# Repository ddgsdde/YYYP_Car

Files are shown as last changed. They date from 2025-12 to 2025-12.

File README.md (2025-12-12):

# 智能车循迹系统 - Smart Car Line Follower System

## 📋 项目概述

这是一个**简化且稳定**的智能车循迹控制系统，基于ESP32-S3开发，专注于**高性能PID循迹控制**。

### 🎯 设计理念
- **专注核心功能**：纯循迹，无额外任务干扰
- **PID+权重算法**：精确控制，平滑跟线
- **实时可调参数**：Web界面动态调整，无需重新编译
- **增强稳定性**：完善的异常处理和状态机设计
- **调试友好**：三级调试系统（串口+OLED+Web）

## ✨ 核心功能

1. **权重+PID循迹** - 8通道加权位置计算 + PID差速控制
2. **按键启停控制** - 一键启动/停止，长按重置统计
3. **Web实时调试** - 参数在线调整、传感器监控、手动控制
4. **动态速度调整** - 根据偏差自动调整基础速度
5. **智能丢线处理** - 基于历史位置的搜索策略
6. **运行统计** - 循环频率、运行时间、里程记录

## 🔧 硬件配置

### 主控
- ESP32-S3-R8N16 (8MB PSRAM + 16MB Flash)

### 传感器
- 8通道循迹传感器模块 (UART通信，115200波特率)
- 0.96寸 OLED显示屏 (SSD1306)
- VL53L0X 激光测距模块
- 超声波测距模块 (3.3V)

### 执行器
- 2个AS4950驱动的减速电机 (减速比21.7)
- AB相编码器 (11PPR)
- 声光报警器
- 舵机 (可选)

### 车辆参数
- 车长: 15cm
- 车宽: 19.18cm  
- 轮胎直径: 67.6mm
- 轮胎宽度: 26.4mm

## 📦 物料清单 (BOM)

1. **PCB**: 查看嘉立创`EDA`工程的`BOM`表（注意：第一个板不用打，超尺寸了已弃用）。**PCB工程文件位于项目根目录的 `Files/` 文件夹中。**
2. **车架**: `3D`打印车底座。**3D打印模型文件位于项目根目录的 `Files/` 文件夹中。**
3. **动力系统**: 两个编码器电机 + 轮胎等
4. **测距模块**: `VL53L0X`激光测距模块
5. **避障模块**: 超声波模块（**必须使用3.3V供电**）
6. **辅助轮**: 一个小万向轮
7. **连接线**: 杜邦线等，按照自己需求购买线缆连接

## ⚠️ 组装注意事项

1. **焊接测试**: 焊接完毕后测试正常直接安装即可。
2. **MCU焊接**: 在焊接`mcu`模块时，如果使用锡膏要注意按键是否短路，短路会导致`esp32s3`无法正常启动。
3. **开发环境**: `Vscode`中必须安装`PlatformIO`拓展，编译后使用USB连接编译并烧录固件。
4. **烧录供电**: 烧录固件时主板必须处于通电状态。
5. **传感器安装**: 激光传感器建议用双面胶和胶带粘在侧方。

## 📌 引脚连接 (GPIO对应表)

| GPIO | 功能 | 说明 |
|---|---|---|
| IO8  | MS1 | 舵机PWM |
| IO3  | ECHO | 超声波 |
| IO18 | TX | 循迹模块 |
| IO46 | O | 声光报警高电平 |
| IO17 | RX | 循迹模块 |
| IO9  | 1A | 右电机编码器 |
| IO16 | SDA | 外设 (VL53L0X)  |
| IO10 | 1B | 右电机编码器 |
| IO15 | SCL | 外设 (VL53L0X)  |
| IO11 | 2A | 左电机编码器 |
| IO7  | 2I1 | 左电机 |
| IO12 | 2B | 左电机编码器 |
| IO6  | 2I2 | 左电机 |
| IO13 | SCL2 | 屏幕 |
| IO5  | 1I1 | 右电机 |
| IO14 | SDA2 | 屏幕 |
| IO4  | 1I2 | 右电机 |
| IO1  | SW1 | 实体按键（按下接通GND） |
| IO2  | TOUCH2 | 触摸按键 |
| IO45 | EN3V3  | 3.3V外设供电使能 |
| IO39 | TRIG | 超声波 |

## 🚀 快速开始与使用指南

### 1. 推荐流程
1. **硬件准备**: 定制PCB并完成焊接操作，测试`5v，3.3v`电压及电机驱动是否工作正常。
2. **固件烧录**: 
   - **下载编辑器**: 前往官网下载并安装 [Visual Studio Code](https://code.visualstudio.com/)。
   - **安装插件**: 打开 VSCode，在左侧扩展商店 (Extensions) 搜索 `PlatformIO IDE` 并安装（安装过程可能较慢，请耐心等待完成后重启软件）。
   - **打开项目**: 使用 VSCode 打开本项目的文件夹。
   - **编译烧录**: 等待左下角加载完毕后，使用 USB 连接主板（确保主板已通电），点击底部状态栏的 ➡️ (Upload) 箭头图标即可自动编译并烧录。
   
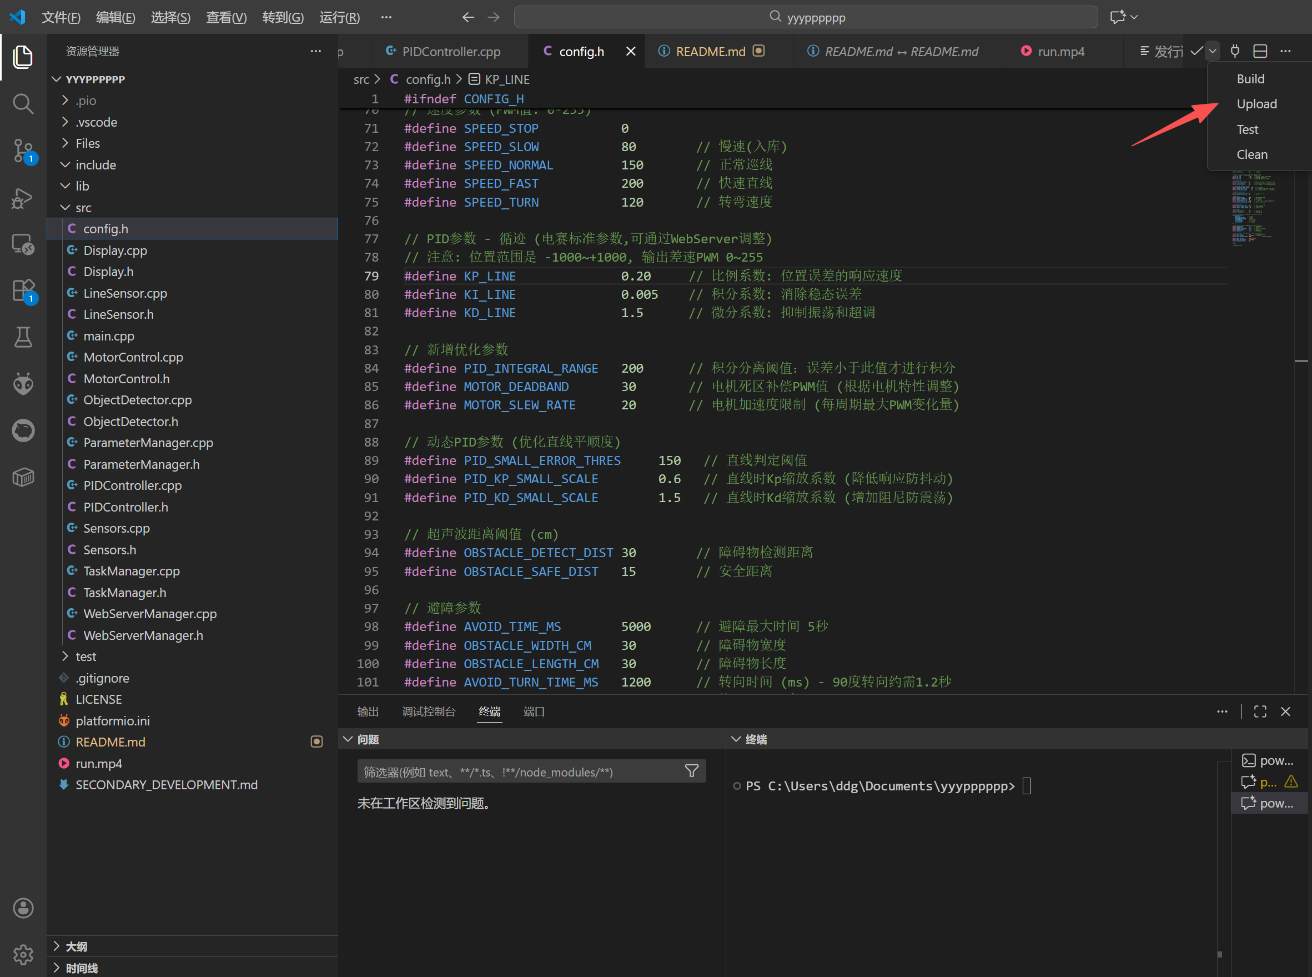
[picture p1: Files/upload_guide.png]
固件烧录指南
   

3. **整车组装**: 打印车模并安装，安装激光传感器等外设。
4. **参数调试**: 开始调参。

### 2. 编译上传

```bash
platformio run --target upload
```

### 3. 连接与调试

1. **WiFi连接**: 系统启动后会自动创建WiFi热点 `SmartCar_AP` (密码: `12345678`)。
2. **Web调试**: 连接WiFi后，浏览器访问 `http://192.168.4.1` 即可进行调试（上位机已内置）。
3. **操作控制**: 
   - **短按**物理按钮即可发车。
   - **再次短按**停止（注意：由于使用任务机制，在执行某些特定任务时可能无法立即停止）。

### 4. 检测传感器

页面会自动检测传感器状态，确保循迹传感器和编码器正常工作。

### 5. 调整参数

在Web界面中实时调整:
- **PID参数** (Kp=0.20, Ki=0.005, Kd=1.5 为推荐起始值)
- **速度参数** (慢速、正常、快速、转弯)
- **传感器权重** (默认 -1000 到 +1000 线性分布)

### 6. 开始循迹

1. 将小车放在黑线上
2. **短按**启动按键 → 开始循迹
3. **再次短按** → 停止循迹
4. **长按2秒** → 重置运行统计

## 📊 Web调试界面功能

### 实时状态监控
- **系统状态**: 运行/待机、运行时间
- **传感器数据**: 循迹位置 (-1000~+1000)、传感器状态 (0xFF)
- **PID调试**: P/I/D 三项实时数值
- **电机数据**: 左右轮速度 (mm/s)、里程 (mm)
- **性能指标**: 循环频率 (Hz)、丢线状态

### 参数实时调整
- **PID参数**: Kp (比例)、Ki (积分)、Kd (微分)
- **速度档位**: 慢速 (80)、正常 (150)、快速 (200)、转弯 (120)
- **传感器权重**: 8个传感器独立权重配置
- **保存功能**: Flash存储，断电不丢失

### 传感器检测
- **自动检测**: 页面加载自动检测所有传感器
- **实时刷新**: 500ms更新频率
- **状态指示**: ✅正常 / ❌异常 / ⏳检测中

### 手动控制
- **方向控制**: 前进、后退、左转、右转
- **特殊动作**: 180°原地转向
- **安全机制**: 暂停自动模式，松开停止

## 🎯 PID循迹算法详解

### 算法流程
```
1. 8通道传感器 → 加权位置计算 (-1000 ~ +1000)
2. 位置 → PID控制器 → 差速输出 (-255 ~ +255)
3. 基础速度 + 差速 → 左右轮速度
4. 动态调速：大偏差减速，小偏差加速
```

### 权重计算
```cpp
传感器: [0] [1] [2] [3] [4] [5] [6] [7]
权重:  -1000-750-500-250 250 500 750 1000
位置 = Σ(传感器i × 权重i) / Σ(传感器i × 1000)
```

### PID计算
```cpp
P项 = Kp × 位置误差       // 快速响应
I项 = Ki × Σ误差 × Δt     // 消除稳态误差
D项 = Kd × (误差变化率)   // 抑制振荡
输出 = P + I + D
```

### 动态速度策略
```cpp
if (|位置| > 700)  → 慢速 (80 PWM)
else if (|位置| > 400) → 中速 (115 PWM)
else → 正常速度 (150 PWM)
```

## ⚙️ PID调试技巧

### 推荐起始参数
```cpp
Kp = 0.20   // 比例：控制响应速度
Ki = 0.005  // 积分：消除稳态偏差
Kd = 1.5    // 微分：抑制振荡
```

### 调试步骤（Ziegler-Nichols方法改进版）

#### 第一步：调Kp
1. 设置 Ki=0, Kd=0
2. 从 Kp=0.1 开始逐渐增加
3. 观察：车子开始响应黑线
4. 继续增加直到出现**轻微振荡**
5. 记录此时的 Kp 值（称为 Ku）
6. 最终设置：**Kp = 0.6 × Ku**

#### 第二步：调Kd
1. 保持 Kp, Ki=0
2. 从 Kd=0.5 开始增加
3. 观察：振荡逐渐减小
4. 继续调整直到**平滑跟线，无振荡**
5. 推荐：**Kd = 1.5 ~ 3.0**

#### 第三步：调Ki（可选）
1. 保持 Kp 和 Kd
2. 从 Ki=0.001 开始增加
3. 观察：直线跑偏情况
4. 如果**无明显跑偏**，Ki保持很小或为0
5. 如果**持续偏向一侧**，增加 Ki
6. 注意：**Ki过大会导致超调**

### 常见问题及解决方案

| 现象 | 可能原因 | 解决方法 |
|---|---|---|
| 🐌 响应慢，转弯不及时 | Kp太小 | 增大Kp (步长0.05) |
| 🌊 左右摇摆严重 | Kp太大或Kd太小 | 减小Kp或增大Kd |
| ↗️ 直线持续偏向一侧 | Ki太小 | 增大Ki (步长0.002) |
| 🔄 过弯冲出赛道 | 速度太快 | 降低speedNormal |
| ⚡ 转弯时振荡 | Kd不足 | 增大Kd (步长0.5) |
| 💥 突然失控 | Ki太大导致积分饱和 | 减小Ki或重置系统 |

### 高级优化技巧

1. **权重调整**
   - 外侧传感器权重 ↑ → 转弯灵敏度 ↑
   - 内侧传感器权重 ↑ → 直线稳定性 ↑
   - 非线性权重：`[-1200, -800, -400, -150, 150, 400, 800, 1200]`

2. **动态速度**
   - 大偏差时自动减速（代码已实现）
   - 可根据赛道调整阈值 (700/400)

3. **丢线处理**
   - 系统已实现基于历史位置的智能搜索
   - 连续3次全白才判定丢线（避免误判）

4. **测试流程**
   ```
   低速测试 → 调PID → 中速测试 → 微调 → 高速测试 → 优化权重
   ```

## 🔍 调试模式

在`src/config.h`中可以开启不同的调试输出:

```cpp
#define DEBUG_SERIAL         true   // 串口调试
#define DEBUG_OLED           true   // OLED显示
#define DEBUG_LINE_SENSOR    false  // 循迹详细信息
#define DEBUG_ENCODER        false  // 编码器输出
#define DEBUG_PID            true   // PID三项数值
```

### 串口输出示例
```
Pos: -450 | P: -90.0 I:  -2.3 D: 120.5 | Out: 28.2 | L: 164 R: 136
Pos:  320 | P:  64.0 I:   1.8 D: -85.3 | Out:-19.5 | L: 130 R: 170
```

### OLED显示内容
```
RUN  T:45s          ← 状态和运行时间
S:0x18 P:0          ← 传感器状态和位置
P:0 I:0 D:0         ← PID三项
L:150 R:150         ← 左右轮速
─────────────────
Dist:12.5m          ← 累计里程
Freq:95Hz           ← 循环频率
```

## 📦 代码结构

```
src/
├── main.cpp              # 主程序和状态机
├── config.h              # 配置参数
├── LineSensor.h/cpp      # 循迹传感器
├── MotorControl.h/cpp    # 电机控制和编码器
├── PIDController.h/cpp   # PID控制器
├── Sensors.h/cpp         # 超声波和激光传感器
├── Display.h/cpp         # OLED显示
├── ParameterManager.h/cpp     # 参数管理和存储
└── WebServerManager.h/cpp     # Web服务器
```

## 🛠️ 依赖库

- ESP32Encoder - 编码器读取
- QuickPID - PID控制
- Adafruit_VL53L0X - 激光测距
- NewPing - 超声波测距
- Adafruit GFX & SSD1306 - OLED显示
- ESPAsyncWebServer - Web服务器
- ArduinoJson - JSON数据处理
- Preferences - 参数持久化存储

## 🎯 比赛任务清单

- [x] 循迹行驶
- [x] 物体长度测量
- [x] 障碍物避障 (偏出时间≤5秒)
- [x] 自动入库停车
- [x] 声光报警
- [x] 实时调试

## 📝 注意事项

1. **首次使用** - 先在测试环境调试PID参数
2. **光照影响** - 循迹传感器对光照敏感,建议现场校准
3. **电池电压** - 确保电池电量充足,电压不足会影响电机性能
4. **Web连接** - 比赛时可以连接Web界面实时监控
5. **参数备份** - 调好参数后记得保存,断电会丢失临时参数

## 🐛 故障排查

### 小车不走
- 检查电机连接
- 检查PWM输出
- 串口监视器查看日志

### 循迹不准
- 调整PID参数
- 检查传感器安装高度
- 查看Web界面传感器状态

### Web连接不上
- 确认WiFi已连接到SmartCar_AP
- 检查IP地址 (192.168.4.1)
- 查看串口输出的IP地址

### 避障失败
- 调整超声波阈值
- 增加避障距离参数
- 检查避障逻辑

## 📈 性能优化建议

1. **速度优化** - 直线段提高速度,弯道降低速度
2. **响应优化** - 根据场地调整PID参数
3. **避障优化** - 根据障碍物大小调整避障路径
4. **测量优化** - 激光传感器采样多次取平均

## 🏆 比赛策略

1. **稳定优先** - 初期以稳定完成为目标
2. **速度提升** - 稳定后逐步提高速度
3. **参数微调** - 根据现场情况微调参数
4. **多次测试** - 比赛前多次完整测试

## 🎬 比赛视频

> 由于 GitHub README 的安全限制，无法直接嵌入仓库内的视频文件进行内联播放。
> 请点击下方链接，跳转到 GitHub 播放器观看：

[**▶️ 点击观看比赛演示视频 (run.mp4)**](https://github.com/ScineceTechAILab/YYYP_Car/blob/master/run.mp4)

## 📞 技术支持

如有问题,请检查:
1. 串口监视器输出 (115200波特率)
2. Web界面实时状态
3. OLED显示屏信息

## 📄 版本信息

- Version: 1.0.0
- Date: 2025-01-13
- Platform: ESP32-S3
- Framework: Arduino

## 📜 开源协议

本项目采用 [GPL-3.0](LICENSE) 开源协议。
您可以自由地使用、修改和分发本项目代码，但必须保留原作者版权声明，且分发的衍生作品也必须采用相同的 GPL-3.0 协议开源。

---

**祝比赛顺利! 🏁**

POWERED BY DDG

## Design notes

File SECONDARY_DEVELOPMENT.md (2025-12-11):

# 智能循迹小车二次开发文档

本文档旨在帮助开发者理解项目架构，并进行二次开发（如添加新功能、修改控制逻辑、增加参数等）。

## 1. 项目简介

本项目是一个基于 ESP32-S3 的智能循迹小车系统，具备以下核心功能：
- **高精度循迹**：基于 PID 算法的黑线循迹。
- **多阶段控制**：支持测距前、测距后使用不同的 PID 和速度参数。
- **智能避障**：基于超声波和编码器的多步避障逻辑（左转->直行->平行->回线）。
- **物块测量**：使用激光测距传感器测量路边物块长度。
- **自动入库**：识别终点并自动入库停车。
- **Web 交互**：通过 WiFi 提供 Web 界面，支持实时参数调整、状态监控和日志查看。

## 2. 开发环境搭建

1.  **IDE**: Visual Studio Code
2.  **插件**: PlatformIO IDE
3.  **硬件**: 4D Systems GEN4-ESP32 16MB (ESP32S3-R8N16) 或兼容 ESP32S3 开发板。
4.  **依赖库** (自动安装):
    - `ESP32Encoder`, `QuickPID` (运动控制)
    - `Adafruit_VL53L0X`, `NewPing` (传感器)
    - `ESPAsyncWebServer`, `ArduinoJson` (网络与数据)
    - `Adafruit SSD1306`, `Adafruit GFX` (OLED 显示)

## 3. 项目结构说明

```text
├── platformio.ini      # PlatformIO 配置文件 (依赖、板卡定义)
├── src/                # 源代码目录
│   ├── main.cpp        # 主程序入口，包含状态机和主循环
│   ├── config.h        # 全局硬件引脚定义和常量
│   ├── ParameterManager.*  # 参数管理 (NVS存储、JSON序列化)
│   ├── WebServerManager.*  # Web 服务器与 WebSocket 通信
│   ├── MotorControl.*      # 电机底层驱动与编码器读取
│   ├── PIDController.*     # PID 算法实现
│   ├── LineSensor.*        # 循迹传感器处理
│   ├── Sensors.*           # 综合传感器管理 (激光、超声波等)
│   ├── ObjectDetector.*    # 物块检测与测量逻辑
│   ├── TaskManager.*       # 任务队列管理
│   └── Display.*           # OLED 显示管理
└── include/            # 头文件目录
```

## 4. 核心架构解析

### 4.1 系统状态机 (`main.cpp`)
系统通过 `SystemState` 枚举管理运行状态：
- `STATE_IDLE`: 待机状态，电机停止。
- `STATE_LINE_FOLLOW`: 循迹模式，核心控制逻辑。
- `STATE_OBSTACLE_AVOID`: 避障模式，执行多步避障动作。
- `STATE_PARKING`: 入库模式，执行停车逻辑。
- `STATE_TESTING`: 测试模式，用于调试特定动作（如转弯、直行）。

### 4.2 参数管理系统 (`ParameterManager`)
所有可配置参数（PID、速度、阈值等）都存储在 `ParameterManager` 中。
- **存储**: 使用 ESP32 `Preferences` (NVS) 掉电保存。
- **交互**: 提供 `toJson()` 和 `fromJson()` 方法，方便与 Web 端交互。

### 4.3 Web 交互系统 (`WebServerManager`)
- 基于 `ESPAsyncWebServer`。
- 前端 HTML/JS 硬编码在 `generateHTML()` 中（为了单文件部署便利）。
- 通过 HTTP GET/POST 接口交换 JSON 数据。

## 5. 常见开发场景指南

### 5.1 如何添加一个新的配置参数？

如果你需要添加一个新的参数（例如 `newParam`），请遵循以下步骤：

1.  **修改 `src/ParameterManager.h`**:
    在 `Parameters` 结构体中添加变量：
    ```cpp
    struct Parameters {
        // ... existing params
        float newParam; // [新增]
    };
    ```

2.  **修改 `src/ParameterManager.cpp`**:
    - 在构造函数中设置默认值：
      ```cpp
      newParam = 1.0f;
      ```
    - 在 `load()` 方法中读取 NVS：
      ```cpp
      newParam = prefs.getFloat("newParam", 1.0f);
      ```
    - 在 `save()` 方法中写入 NVS：
      ```cpp
      prefs.putFloat("newParam", newParam);
      ```
    - 在 `toJson()` 方法中添加到 JSON：
      ```cpp
      doc["newParam"] = newParam;
      ```
    - 在 `fromJson()` 方法中从 JSON 读取：
      ```cpp
      if (doc.containsKey("newParam")) newParam = doc["newParam"];
      ```

3.  **修改 `src/WebServerManager.cpp`**:
    在 `generateHTML()` 的 JavaScript 部分，找到 `loadParams` 和 `saveParams` 函数，添加对应的字段映射，并在 HTML 表单中添加 `<input>` 元素。

### 5.2 如何修改避障逻辑？

避障逻辑位于 `src/main.cpp` 的 `handleObstacleAvoidance()` 函数中。
它是一个基于 `avoidSubState` 的子状态机：
1.  `AVOID_TURN_LEFT`: 左转离开赛道。
2.  `AVOID_FORWARD_OUT`: 直行一段距离。
3.  `AVOID_TURN_RIGHT_1`: 右转平行。
4.  ...

**修改建议**:
- 调整 `ParameterManager` 中的 `avoid*` 相关参数（如 `avoidTurn1Dist`）通常能满足大部分需求。
- 如果需要修改动作顺序，请直接修改 `switch(avoidSubState)` 中的逻辑跳转。

### 5.3 如何添加新的传感器？

1.  **硬件连接**: 确定引脚并在 `src/config.h` 中定义。
2.  **驱动封装**: 建议在 `src/Sensors.h/.cpp` 中添加初始化和读取代码，或者创建新的类。
3.  **数据集成**: 在 `src/main.cpp` 的 `updateSensors()` 中调用更新，并通过 `getSystemStatus()` 将数据发送到 Web 端以便调试。

## 6. 调试技巧

- **串口调试**: 波特率 `115200`。系统启动时会打印详细信息。
- **Web 日志**: 浏览器访问小车 IP，页面底部有实时 Console 日志，通过 `webServer.addLog()` 输出。
- **OLED 显示**: 实时显示 PID 输出、传感器状态和 IP 地址。
- **状态监控**: Web 界面会以 5Hz 频率刷新 JSON 状态，包含所有传感器数据和内部变量。

## 7. 编译与上传

在 VS Code 终端中运行：

- **编译**: `platformio run`
- **上传**: `platformio run --target upload`
- **清理**: `platformio run --target clean`

## 8. 注意事项

- **并发安全**: `WebServer` 回调在独立任务中运行，修改全局变量（如 `currentState`）时需注意线程安全，或使用标志位（如 `pendingManualCmd`）在主循环中处理。
- **NVS 寿命**: 避免在循环中高频调用 `params.save()`，这会损耗 Flash 寿命。仅在 Web 端点击“保存”时调用。

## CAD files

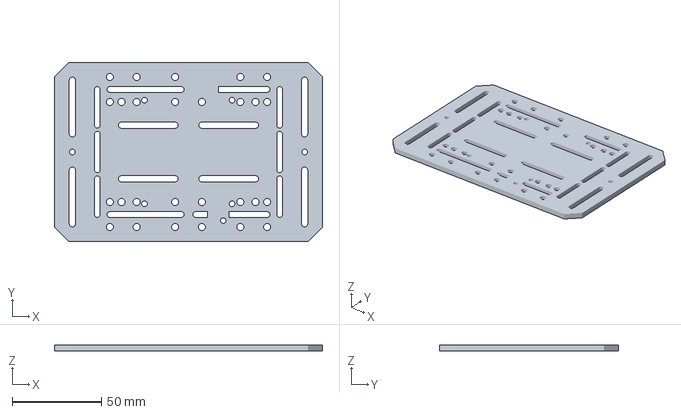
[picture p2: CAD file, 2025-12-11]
Files/3D/组合体.3mf
150.0 x 100.0 x 3.50 mm

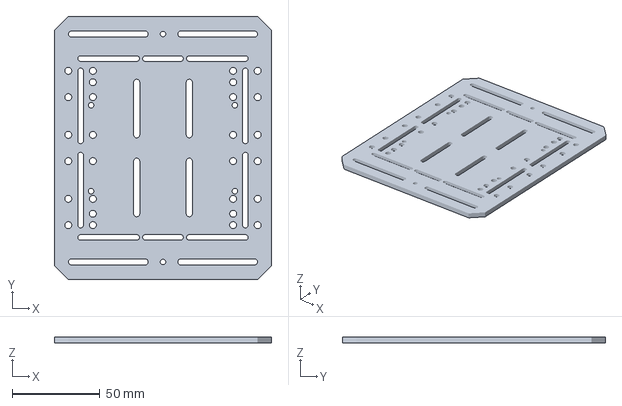
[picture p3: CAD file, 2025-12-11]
Files/3D/组合放大体.3mf
124.0 x 150.0 x 3.50 mm

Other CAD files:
Files/3D/组合体.stl

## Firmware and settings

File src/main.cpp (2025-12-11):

#include <Arduino.h>
#include <ArduinoJson.h>
#include "config.h"
#include "LineSensor.h"
#include "MotorControl.h"
#include "Sensors.h"
#include "Display.h"
#include "PIDController.h"
#include "ParameterManager.h"
#include "WebServerManager.h"
#include "ObjectDetector.h"
#include "TaskManager.h"

// 全局对象
LineSensor lineSensor;
MotorControl motor;
Sensors sensors;
Display display;
PIDController pidController(KP_LINE, KI_LINE, KD_LINE);
PIDController encoderPid(1.0, 0, 0); // 编码器直线保持PID
ParameterManager params;
WebServerManager webServer(&params);
ObjectDetector objectDetector(&sensors, &motor);
TaskManager taskManager;

// 状态变量
SystemState currentState = STATE_IDLE;
bool systemRunning = false;  // 系统运行标志

// 跨任务通信标志 (解决并发崩溃问题)
volatile bool pendingTestTurn = false;
volatile bool pendingTestStraight = false;
volatile bool pendingTestAvoid = false;
volatile bool pendingTestParking = false;
enum ManualCommand { CMD_NONE, CMD_STOP, CMD_FORWARD, CMD_BACKWARD, CMD_LEFT, CMD_RIGHT, CMD_TURN_180 };
volatile ManualCommand pendingManualCmd = CMD_NONE;
volatile float pendingManualValue = 0;

// 障碍物检测计数器
int obstacleDetectCount = 0;  // 检测到的障碍物次数
bool obstacleDetectionEnabled = false;  // 是否启用障碍物检测

// 避障子状态
enum AvoidanceSubState {
    AVOID_NONE,
    AVOID_TURN_LEFT,      // 1. 左转离开赛道
    AVOID_FORWARD_OUT,    // 2. 直行离开赛道 (距离可调)
    AVOID_TURN_RIGHT_1,   // 3. 右转 (平行于赛道)
    AVOID_FORWARD_PARALLEL, // 4. 直行 (平行移动)
    AVOID_TURN_RIGHT_2,   // 5. 右转 (面向赛道)
    AVOID_FORWARD_IN,     // 6. 直行寻找黑线
    AVOID_TURN_LEFT_ALIGN // 7. 左转对齐赛道
};
AvoidanceSubState avoidSubState = AVOID_NONE;
unsigned long avoidStateStartTime = 0;
float avoidStateStartDistance = 0;
float avoidStartLeftDist = 0;
float avoidStartRightDist = 0;

// 避障后状态变量
unsigned long avoidanceFinishTime = 0; // 避障完成时间
bool postAvoidanceStable = false;      // 避障后是否已稳定(持续1秒识线)

// 停车子状态
enum ParkingSubState {
    PARK_APPROACH,      // 接近 (减速)
    PARK_VERY_SLOW,     // 极慢速
    PARK_STOP,          // 停止
    PARK_ALARM          // 报警
};
ParkingSubState parkingSubState = PARK_APPROACH;
unsigned long parkingStateStartTime = 0;

// 测试模式状态
enum TestSubState {
    TEST_NONE,
    TEST_TURN_90,
    TEST_STRAIGHT_1M
};
TestSubState currentTestState = TEST_NONE;
unsigned long testStartTime = 0;

// 按键状态机变量
unsigned long buttonPressStart = 0;
bool buttonWasPressed = false;
bool buttonProcessed = false;  // 防止重复触发

// 手动控制变量
bool manualControlActive = false;
unsigned long manualControlEndTime = 0;

// 循迹统计变量
unsigned long lineFollowStartTime = 0;
unsigned long totalLineFollowTime = 0;
uint32_t loopCounter = 0;
unsigned long lastStatsTime = 0;

// 状态回调函数
String getSystemStatus() {
    JsonDocument doc;
    
    // 系统状态
    const char* stateNames[] = {"IDLE", "LINE_FOLLOW", "OBSTACLE_AVOID", "PARKING", "FINISHED", "TESTING"};
    if (currentState >= 0 && currentState < sizeof(stateNames)/sizeof(stateNames[0])) {
        doc["state"] = stateNames[currentState];
    } else {
        doc["state"] = "UNKNOWN";
    }
    doc["uptime"] = millis() / 1000;
    doc["running"] = systemRunning;
    doc["loopFreq"] = loopCounter;  // 循环频率
    
    // 传感器数据
    JsonObject sensor = doc["sensor"].to<JsonObject>();
    sensor["linePos"] = lineSensor.getLinePosition();
    sensor["lineStates"] = lineSensor.getRawStates();
    sensor["dataReady"] = lineSensor.isDataReady();
    sensor["lostLine"] = lineSensor.isLostLine();
    sensor["laserDist"] = sensors.getLaserDistance();
    sensor["laserReady"] = sensors.isLaserReady();
    sensor["ultraDist"] = sensors.getUltrasonicDistance();
    
    // 电机数据
    JsonObject mot = doc["motor"].to<JsonObject>();
    mot["speedL"] = motor.getLeftSpeed();
    mot["speedR"] = motor.getRightSpeed();
    mot["distL"] = motor.getLeftDistance();
    mot["distR"] = motor.getRightDistance();
    mot["encL"] = motor.getLeftEncoder();
    mot["encR"] = motor.getRightEncoder();
    
    // PID调试数据
    JsonObject pid = doc["pid"].to<JsonObject>();
    pid["pTerm"] = pidController.getP();
    pid["iTerm"] = pidController.getI();
    pid["dTerm"] = pidController.getD();
    pid["error"] = pidController.getError();
    
    // 运行统计
    doc["totalTime"] = totalLineFollowTime / 1000;
    
    // 编码器调试信息
    JsonObject encDebug = doc["encDebug"].to<JsonObject>();
    encDebug["left"] = motor.getLeftDistance();
    encDebug["right"] = motor.getRightDistance();
    encDebug["diff"] = motor.getLeftDistance() - motor.getRightDistance();
    
    // 物块检测状态
    JsonObject detection = doc["detection"].to<JsonObject>();
    detection["active"] = objectDetector.isDetecting();
    detection["completed"] = objectDetector.isCompleted();
    if (objectDetector.isCompleted()) {
        ObjectMeasurement result = objectDetector.getResult();
        detection["length"] = result.length;
        detection["avgDist"] = result.avgDistance;
        detection["valid"] = result.valid;
        detection["duration"] = result.duration; // 新增：检测持续时间
        // 传递原始长度，避免前端反向计算误差
        float rawLen = (result.endPos - result.startPos);
        detection["rawLength"] = rawLen;
    }
    
    // 任务管理状态
    JsonObject tasks = doc["tasks"].to<JsonObject>();
    tasks["executing"] = taskManager.isExecuting();
    tasks["current"] = taskManager.getCurrentTaskIndex();
    tasks["total"] = taskManager.getTotalTasks();
    
    String output;
    serializeJson(doc, output);
    return output;
}

// 任务执行器 - 启动任务
bool executeTask(Task* task) {
    if (!task) return false;
    
    switch (task->type) {
        case TASK_LINE_FOLLOW:
            // 开启循迹模式
            systemRunning = true;
            currentState = STATE_LINE_FOLLOW;
            return true;
            
        case TASK_MEASURE_OBJECT:
            // 启动物块测量
            objectDetector.startDetection(
                task->params.laserBaseline, 
                task->params.laserThreshold
            );
            return true;
            
        case TASK_FORWARD:
            // 前进指定距离
            motor.resetEncoders();
            motor.setBothSpeed(task->params.speed > 0 ? task->params.speed : params.speedNormal);
            return true;
            
        case TASK_STOP:
            // 停止
            systemRunning = false;
            motor.stop();
            return true;
            
        case TASK_DELAY:
            // 延时（通过startTime判断）
            return true;
            
        case TASK_BEEP:
            // 蜂鸣
            // sensors.beep(task->params.duration > 0 ? task->params.duration : 100);
            return true;
            
        default:
            Serial.printf("⚠ Unknown task type: %d\n", task->type);
            return false;
    }
}

// 任务完成检查器
bool checkTaskCompletion(Task* task) {
    if (!task) return true;
    
    switch (task->type) {
        case TASK_LINE_FOLLOW:
            // 循迹任务需要手动停止或达到距离
            if (task->params.distance > 0) {
                float avgDist = motor.getAverageDistance();
                return avgDist >= task->params.distance;
            }
            return false;  // 无限循迹，需要其他条件停止
            
        case TASK_MEASURE_OBJECT:
            // 检查物块测量是否完成
            return objectDetector.isCompleted() || 
                   (millis() - task->startTime > 30000);  // 30秒超时
            
        case TASK_FORWARD:
            // 检查是否达到目标距离
            if (task->params.distance > 0) {
                float avgDist = motor.getAverageDistance();
                if (avgDist >= task->params.distance) {
                    motor.stop();
                    return true;
                }
            } else if (task->params.duration > 0) {
                // 按时间前进
                if (millis() - task->startTime >= task->params.duration) {
                    motor.stop();
                    return true;
                }
            }
            return false;
            
        case TASK_STOP:
            return true;  // 立即完成
            
        case TASK_DELAY:
            return (millis() - task->startTime) >= task->params.duration;
            
        case TASK_BEEP:
            return true;  // 立即完成
            
        default:
            return true;
    }
}

// 运动控制回调 (仅设置标志位，不在中断/异步任务中执行逻辑)
void handleMotionCommand(String action, float value) {
    // 映射字符串命令到枚举，确保原子操作
    if (action == "stop") pendingManualCmd = CMD_STOP;
    else if (action == "forward") pendingManualCmd = CMD_FORWARD;
    else if (action == "backward") pendingManualCmd = CMD_BACKWARD;
    else if (action == "left") pendingManualCmd = CMD_LEFT;
    else if (action == "right") pendingManualCmd = CMD_RIGHT;
    else if (action == "turn_180") pendingManualCmd = CMD_TURN_180;
    
    pendingManualValue = value;
}

// 处理挂起的命令 (在主循环中调用)
void processPendingCommands() {
    // 1. 处理测试命令
    if (pendingTestTurn) {
        pendingTestTurn = false;
        if (!systemRunning) {
            Serial.println("CMD: Starting Turn 90 Test");
            currentState = STATE_TESTING;
            currentTestState = TEST_TURN_90;
            testStartTime = millis();
            motor.resetEncoders();
            systemRunning = true;
        }
    }
    
    if (pendingTestStraight) {
        pendingTestStraight = false;
        if (!systemRunning) {
            Serial.println("CMD: Starting Straight 1m Test");
            currentState = STATE_TESTING;
            currentTestState = TEST_STRAIGHT_1M;
            testStartTime = millis();
            motor.resetEncoders();
            encoderPid.reset();
            encoderPid.setGains(params.encKp, params.encKi, params.encKd);
            systemRunning = true;
        }
    }
    
    if (pendingTestAvoid) {
        pendingTestAvoid = false;
        if (!systemRunning) {
            Serial.println("CMD: Starting Avoidance Test");
            // 直接进入避障状态
            currentState = STATE_OBSTACLE_AVOID;
            avoidSubState = AVOID_TURN_LEFT;
            avoidStateStartTime = millis();
            motor.resetEncoders();
            avoidStartLeftDist = 0;
            avoidStartRightDist = 0;
            avoidStateStartDistance = 0;
            systemRunning = true;
            // sensors.beep(100);
        }
    }

    if (pendingTestParking) {
        pendingTestParking = false;
        Serial.println("CMD: Starting Parking Test");
        
        // 重置系统状态
        systemRunning = true;
        currentState = STATE_LINE_FOLLOW;
        lineFollowStartTime = millis();
        motor.resetEncoders();
        pidController.reset();
        
        // 设置为入库测试模式
        objectDetector.stopDetection(); // 确保不处于物块检测模式
        obstacleDetectionEnabled = true; // 启用障碍物检测
        obstacleDetectCount = 1; // 假装已经避过第一个障碍物，下一个就是车库
        
        // sensors.beep(100);
        // delay(50);
        // sensors.beep(100);
        display.showDebug("TEST PARKING\nSearching...");
    }
    
    // 2. 处理手动控制命令
    if (pendingManualCmd != CMD_NONE) {
        ManualCommand cmd = pendingManualCmd;
        float val = pendingManualValue;
        pendingManualCmd = CMD_NONE; // 清除标志
        
        // 执行逻辑
        if (cmd == CMD_STOP) {
            motor.stop();
            manualControlActive = false;
            if (systemRunning) Serial.println("Manual Stop");
        } else {
            // 激活手动控制
            if (systemRunning) {
                Serial.println("Auto mode paused for manual control");
            }
            manualControlActive = true;
            
            int moveSpeed = (val > 0) ? (int)val : params.speedNormal;
            int turnSpeed = params.speedTurn;
            
            switch (cmd) {
                case CMD_FORWARD:
                    motor.setBothSpeed(moveSpeed);
                    manualControlEndTime = millis() + 10000;
                    break;
                case CMD_BACKWARD:
                    motor.setBothSpeed(-moveSpeed);
                    manualControlEndTime = millis() + 10000;
                    break;
                case CMD_LEFT:
                    motor.setLeftSpeed(-turnSpeed);
                    motor.setRightSpeed(turnSpeed);
                    manualControlEndTime = millis() + 10000;
                    break;
                case CMD_RIGHT:
                    motor.setLeftSpeed(turnSpeed);
                    motor.setRightSpeed(-turnSpeed);
                    manualControlEndTime = millis() + 10000;
                    break;
                case CMD_TURN_180:
                    motor.setLeftSpeed(turnSpeed);
                    motor.setRightSpeed(-turnSpeed);
                    manualControlEndTime = millis() + 1200;
                    break;
                default: break;
            }
        }
    }
}
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
void loop() {
    // 处理Web挂起的命令
    processPendingCommands();

    // 更新传感器数据
    updateSensors();
    
    // 按键状态机 - 改进的防抖和切换逻辑
    bool buttonNow = sensors.isButtonPressed();
    
    if (buttonNow && !buttonWasPressed && !buttonProcessed) {
        // 按钮刚按下
        buttonPressStart = millis();
        buttonWasPressed = true;
    } else if (!buttonNow && buttonWasPressed && !buttonProcessed) {
        // 按钮刚释放
        unsigned long pressDuration = millis() - buttonPressStart;
        
        if (pressDuration >= 50 && pressDuration < 2000) {
            // 有效短按：切换运行状态
            systemRunning = !systemRunning;
            buttonProcessed = true;
            
            if (systemRunning) {
                currentState = STATE_LINE_FOLLOW;
                lineFollowStartTime = millis();
                motor.resetEncoders();
                pidController.reset();  // 重置PID状态
                
                // 重置避障后状态
                avoidanceFinishTime = 0;
                postAvoidanceStable = false;
                
                // 自动启动物块检测
                currentState = STATE_LINE_FOLLOW;
                lineFollowStartTime = millis();
                motor.resetEncoders();
                pidController.reset();  // 重置PID状态
                
                // 自动启动物块检测
                objectDetector.setFilterSize(params.objectFilterSize);
                objectDetector.setCorrection(params.objectLengthScale, params.objectLengthOffset);
                objectDetector.startDetection(0, params.objectDetectDist);
                
                // 重置障碍物检测状态
                obstacleDetectCount = 0;
                obstacleDetectionEnabled = false;  // 等物块测量完成后再启用
                
                display.showDebug("RUNNING\nPress to stop");
            } else {
                // 停止
                Serial.println("\n=== SYSTEM STOP ===");
                // sensors.beep(200);
                
                motor.stop();
                currentState = STATE_IDLE;
                
                // 停止检测
                if (objectDetector.isDetecting()) {
                    objectDetector.stopDetection();
                }
                
                totalLineFollowTime += millis() - lineFollowStartTime;
                
                Serial.printf("✓ Total run time: %lu seconds\n", totalLineFollowTime / 1000);
                display.showDebug("STOPPED\nPress to start");
            }
        } else if (pressDuration >= 2000) {
            // 长按：重置统计
            totalLineFollowTime = 0;
            motor.resetEncoders();
            Serial.println("✓ Statistics reset");
            // sensors.beep(50);
            // delay(100);
            // sensors.beep(50);
            // delay(100);
            // sensors.beep(50);
            buttonProcessed = true;
        }
    } else if (!buttonNow && buttonProcessed) {
        // 按钮完全释放后重置处理标志
        buttonProcessed = false;
        buttonWasPressed = false;
    }
    
    // 手动控制模式处理
    if (manualControlActive) {
        if (millis() >= manualControlEndTime) {
            motor.stop();
            manualControlActive = false;
            Serial.println("✓ Manual control completed");
        }
        delay(10);
        return;  // 手动模式下不执行自动逻辑
    }
    
    // 更新任务管理器
    taskManager.update();

    // 定时更新Web状态 (200ms interval) - 解决并发崩溃问题的关键
    // 将状态生成移至主循环，避免Web任务直接访问共享资源
    static unsigned long lastWebUpdate = 0;
    if (millis() - lastWebUpdate > 200) {
        String status = getSystemStatus();
        webServer.updateStatusJson(status);
        lastWebUpdate = millis();
    }
    
    // 状态机
    switch (currentState) {
        case STATE_IDLE:
            motor.stop();
            break;
            
        case STATE_LINE_FOLLOW:
            if (systemRunning) {
                lineFollowControl();
            } else {
                motor.stop();
            }
            break;
            
        case STATE_OBSTACLE_AVOID:
            handleObstacleAvoidance();
            break;
            
        case STATE_PARKING:
            handleParking();
            break;
            
        case STATE_FINISHED:
            motor.stop();
            break;

        case STATE_TESTING:
            handleTestMode();
            break;
    }
    
    // 更新显示
#if DEBUG_OLED
    static unsigned long lastDisplayUpdate = 0;
    if (millis() - lastDisplayUpdate > 100) {
        int16_t linePos = lineSensor.getLinePosition();
        uint8_t states = lineSensor.getRawStates();
        
        display.clear();
        Adafruit_SSD1306* oled = display.getDisplay();
        if (oled) {
            oled->setCursor(0, 0);
            oled->setTextSize(1);
            
            // 第一行：状态
            oled->print(systemRunning ? "RUN " : "IDLE");
            oled->printf(" T:%lus\n", (millis() - lineFollowStartTime) / 1000);
            
            // 第二行：传感器状态
            oled->printf("S:0x%02X P:%d\n", states, linePos);
            
            // 第三行：PID输出
            oled->printf("P:%.0f I:%.0f D:%.0f\n", 
                pidController.getP(), 
                pidController.getI(), 
                pidController.getD());
            
            // 第四行：电机速度
            oled->printf("L:%d R:%d\n", 
                (int)motor.getLeftSpeed(), 
                (int)motor.getRightSpeed());
            
            // 分隔线
            oled->drawLine(0, 32, 128, 32, SSD1306_WHITE);
            
            // 如果有测量结果，优先显示结果
            if (objectDetector.getResult().length > 0) {
                oled->setCursor(0, 36);
                oled->setTextSize(1);
                oled->print("Len:");
                oled->setCursor(30, 34); // 稍微调整位置以适应大字体
                oled->setTextSize(3);    // 使用更大的字体
                oled->print((int)objectDetector.getResult().length);
                oled->setTextSize(1);
                oled->print("mm");
            } else {
                // 下半部分：里程和激光距离
                oled->setCursor(0, 36);
                oled->setTextSize(1);
                oled->printf("Dist:%.1fm\n", motor.getAverageDistance() / 1000.0);
                
                // 激光距离
                uint16_t laserDist = sensors.getLaserDistance();
                oled->printf("Laser:%dmm\n", laserDist);
                
                oled->printf("Freq:%dHz", loopCounter);
            }
        }
        
        display.update();
        lastDisplayUpdate = millis();
    }
#endif
    
    // 移除固定延时，全速运行
    // delay(10); 
}

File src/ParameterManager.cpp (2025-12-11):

#include "ParameterManager.h"
#include <ArduinoJson.h>

ParameterManager::ParameterManager() {
    // 默认值 (Phase 1)
    kp = KP_LINE;
    ki = KI_LINE;
    kd = KD_LINE;
    
    // 默认值 (Phase 2) - 默认与Phase 1相同
    kpPost = KP_LINE;
    kiPost = KI_LINE;
    kdPost = KD_LINE;
    
    speedSlow = SPEED_SLOW;
    speedNormal = SPEED_NORMAL;
    speedFast = SPEED_FAST;
    speedTurn = SPEED_TURN;
    
    speedNormalPost = SPEED_NORMAL;
    speedFastPost = SPEED_FAST;
    speedTurnPost = SPEED_TURN;
    
    obstacleDetectDist = OBSTACLE_DETECT_DIST;
    objectDetectDist = OBJECT_DETECT_DIST;
    
    avoidTurnDist = 100;
    avoidForwardDist = 400;
    avoidParallelDist = 500;
    avoidSpeed = SPEED_NORMAL;
    avoidTurnSpeed = SPEED_TURN;
    avoidKp = 2.0;
    avoidFinalTurnDist = 118.0;
    avoidTurn1Dist = 118.0;
    avoidTurn2Dist = 118.0;
    avoidTurn3Dist = 118.0;
    avoidSearchDist = 800;
    
    parkingDistSlow = 60;
    parkingDistVerySlow = 30;
    parkingDistStop = 10;
    parkingSpeedSlow = 100;
    parkingSpeedVerySlow = 60;
    
    motorLeftCalib = 1.0;
    motorRightCalib = 1.0;
    
    // 高级PID默认值
    pidIntegralRange = PID_INTEGRAL_RANGE;
    motorDeadband = MOTOR_DEADBAND;
    pidSmallErrorThres = PID_SMALL_ERROR_THRES;
    pidKpSmallScale = PID_KP_SMALL_SCALE;
    pidKdSmallScale = PID_KD_SMALL_SCALE;
    
    // 物体测量默认值（优先保证稳定性）
    objectFilterSize = 5;          // 5点滤波，平衡稳定性与响应
    objectLengthScale = OBJECT_LENGTH_SCALE;
    objectLengthOffset = OBJECT_LENGTH_OFFSET;
    objectDeviationCorrection = 0.0;

    // 编码器闭环参数默认值
    encKp = 1.0;   // 差速修正比例
    encKi = 0.0;
    encKd = 0.0;
    // 轮距15cm，原地旋转90度，单轮行程 = pi * 150 * (90/360) ≈ 117.8mm
    turn90Dist = 118.0; 

    // 避障步骤系数默认值
    avoidS1_L = 1.0; avoidS1_R = 1.0;
    avoidS2_L = 1.0; avoidS2_R = 1.0;
    avoidS3_L = 1.0; avoidS3_R = 1.0;
    avoidS4_L = 1.0; avoidS4_R = 1.0;
    avoidS5_L = 1.0; avoidS5_R = 1.0;
    avoidS6_L = 1.0; avoidS6_R = 1.0;
    
    // 传感器权重默认值
    sensorWeights[0] = -1000;
    sensorWeights[1] = -700;
    sensorWeights[2] = -400;
    sensorWeights[3] = -100;
    sensorWeights[4] = 100;
    sensorWeights[5] = 400;
    sensorWeights[6] = 700;
    sensorWeights[7] = 1000;
}

void ParameterManager::begin() {
    preferences.begin("smartcar", false);
    load();
}

void ParameterManager::save() {
    preferences.putFloat("kp", kp);
    preferences.putFloat("ki", ki);
    preferences.putFloat("kd", kd);
    
    preferences.putFloat("kpPost", kpPost);
    preferences.putFloat("kiPost", kiPost);
    preferences.putFloat("kdPost", kdPost);
    
    preferences.putInt("speedSlow", speedSlow);
    preferences.putInt("speedNormal", speedNormal);
    preferences.putInt("speedFast", speedFast);
    preferences.putInt("speedTurn", speedTurn);
    
    preferences.putInt("spdNormPost", speedNormalPost);
    preferences.putInt("spdFastPost", speedFastPost);
    preferences.putInt("spdTurnPost", speedTurnPost);
    
    preferences.putInt("obstacleDist", obstacleDetectDist);
    preferences.putInt("objectDist", objectDetectDist);
    
    preferences.putInt("avoidTurn", avoidTurnDist);
    preferences.putInt("avoidForward", avoidForwardDist);
    preferences.putInt("avoidParallel", avoidParallelDist);
    preferences.putInt("avoidSpeed", avoidSpeed);
    preferences.putInt("avoidTurnSpd", avoidTurnSpeed);
    preferences.putFloat("avoidKp", avoidKp);
    preferences.putFloat("avoidFinal", avoidFinalTurnDist);
    preferences.putFloat("avoidTurn1", avoidTurn1Dist);
    preferences.putFloat("avoidTurn2", avoidTurn2Dist);
    preferences.putFloat("avoidTurn3", avoidTurn3Dist);
    preferences.putInt("avoidSearch", avoidSearchDist);
    
    preferences.putFloat("avS1L", avoidS1_L); preferences.putFloat("avS1R", avoidS1_R);
    preferences.putFloat("avS2L", avoidS2_L); preferences.putFloat("avS2R", avoidS2_R);
    preferences.putFloat("avS3L", avoidS3_L); preferences.putFloat("avS3R", avoidS3_R);
    preferences.putFloat("avS4L", avoidS4_L); preferences.putFloat("avS4R", avoidS4_R);
    preferences.putFloat("avS5L", avoidS5_L); preferences.putFloat("avS5R", avoidS5_R);
    preferences.putFloat("avS6L", avoidS6_L); preferences.putFloat("avS6R", avoidS6_R);
    
    preferences.putInt("pkDistSlow", parkingDistSlow);
    preferences.putInt("pkDistVSlow", parkingDistVerySlow);
    preferences.putInt("pkDistStop", parkingDistStop);
    preferences.putInt("pkSpdSlow", parkingSpeedSlow);
    preferences.putInt("pkSpdVSlow", parkingSpeedVerySlow);
    
    preferences.putFloat("motorLCalib", motorLeftCalib);
    preferences.putFloat("motorRCalib", motorRightCalib);
    
    preferences.putInt("pidIntRange", pidIntegralRange);
    preferences.putInt("deadband", motorDeadband);
    preferences.putInt("smallErr", pidSmallErrorThres);
    preferences.putFloat("kpScale", pidKpSmallScale);
    preferences.putFloat("kdScale", pidKdSmallScale);
    
    preferences.putInt("objFilter", objectFilterSize);
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

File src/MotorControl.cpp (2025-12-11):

#include "MotorControl.h"

MotorControl::MotorControl() {
    lastLeftCount = 0;
    lastRightCount = 0;
    lastUpdateTime = 0;
    leftSpeed = 0;
    rightSpeed = 0;
    leftCalib = 1.0;
    rightCalib = 1.0;
    deadband = 0;
}

void MotorControl::begin() {
    // 配置电机控制引脚
    pinMode(PIN_MOTOR_L_I1, OUTPUT);
    pinMode(PIN_MOTOR_L_I2, OUTPUT);
    pinMode(PIN_MOTOR_R_I1, OUTPUT);
    pinMode(PIN_MOTOR_R_I2, OUTPUT);
    
    // 初始化编码器
    ESP32Encoder::useInternalWeakPullResistors = puType::up;
    leftEncoder.attachFullQuad(PIN_ENCODER_L_A, PIN_ENCODER_L_B);
    rightEncoder.attachFullQuad(PIN_ENCODER_R_A, PIN_ENCODER_R_B);
    leftEncoder.clearCount();
    rightEncoder.clearCount();
    
    // 设置PWM
    setupPWM();
    
    stop();
    Serial.println("Motor control initialized");
}

void MotorControl::setupPWM() {
    ledcSetup(PWM_CHANNEL_L1, PWM_FREQ, PWM_RESOLUTION);
    ledcSetup(PWM_CHANNEL_L2, PWM_FREQ, PWM_RESOLUTION);
    ledcSetup(PWM_CHANNEL_R1, PWM_FREQ, PWM_RESOLUTION);
    ledcSetup(PWM_CHANNEL_R2, PWM_FREQ, PWM_RESOLUTION);
    
    ledcAttachPin(PIN_MOTOR_L_I1, PWM_CHANNEL_L1);
    ledcAttachPin(PIN_MOTOR_L_I2, PWM_CHANNEL_L2);
    ledcAttachPin(PIN_MOTOR_R_I1, PWM_CHANNEL_R1);
    ledcAttachPin(PIN_MOTOR_R_I2, PWM_CHANNEL_R2);
}

void MotorControl::setPWM(uint8_t channel1, uint8_t channel2, int speed) {
    speed = constrain(speed, -255, 255);
    
    int outputPWM = 0;
    if (speed > 0) {
        // 死区补偿映射
        outputPWM = map(speed, 1, 255, deadband, 255);
        ledcWrite(channel1, outputPWM);
        ledcWrite(channel2, 0);
    } else if (speed < 0) {
        outputPWM = map(-speed, 1, 255, deadband, 255);
        ledcWrite(channel1, 0);
        ledcWrite(channel2, outputPWM);
    } else {
        // 同时低电平滑行
        ledcWrite(channel1, 0);
        ledcWrite(channel2, 0);
    }
}

void MotorControl::setLeftSpeed(int speed) {
    int calibratedSpeed = (int)(speed * leftCalib);
    setPWM(PWM_CHANNEL_L1, PWM_CHANNEL_L2, calibratedSpeed);
}

void MotorControl::setRightSpeed(int speed) {
    int calibratedSpeed = (int)(speed * rightCalib);
    setPWM(PWM_CHANNEL_R1, PWM_CHANNEL_R2, calibratedSpeed);
}

void MotorControl::setBothSpeed(int speed) {
    setLeftSpeed(speed);
    setRightSpeed(speed);
}

void MotorControl::setDifferentialSpeed(int baseSpeed, int turnAdjust) {
    // turnAdjust: 负数左转,正数右转
    int leftSpeed = baseSpeed - turnAdjust;
    int rightSpeed = baseSpeed + turnAdjust;
    
    setLeftSpeed(leftSpeed);
    setRightSpeed(rightSpeed);
}

void MotorControl::stop() {
    ledcWrite(PWM_CHANNEL_L1, 0);
    ledcWrite(PWM_CHANNEL_L2, 0);
    ledcWrite(PWM_CHANNEL_R1, 0);
    ledcWrite(PWM_CHANNEL_R2, 0);
}

void MotorControl::brake() {
    // 同时高电平刹车
    ledcWrite(PWM_CHANNEL_L1, 255);
    ledcWrite(PWM_CHANNEL_L2, 255);
    ledcWrite(PWM_CHANNEL_R1, 255);
    ledcWrite(PWM_CHANNEL_R2, 255);
}

long MotorControl::getLeftEncoder() {
    return leftEncoder.getCount();
}

long MotorControl::getRightEncoder() {
    return rightEncoder.getCount();
}

void MotorControl::resetEncoders() {
    leftEncoder.clearCount();
    rightEncoder.clearCount();
    lastLeftCount = 0;
    lastRightCount = 0;
}

float MotorControl::getLeftDistance() {
    return leftEncoder.getCount() * MM_PER_PULSE;
}

float MotorControl::getRightDistance() {
    return rightEncoder.getCount() * MM_PER_PULSE;
}

float MotorControl::getAverageDistance() {
    return (getLeftDistance() + getRightDistance()) / 2.0;
}

void MotorControl::update() {
    unsigned long currentTime = millis();
    float deltaTime = (currentTime - lastUpdateTime) / 1000.0;  // 转换为秒
    
    if (deltaTime >= 0.05) {  // 每50ms更新一次
        long currentLeftCount = leftEncoder.getCount();
        long currentRightCount = rightEncoder.getCount();
        
        long deltaLeft = currentLeftCount - lastLeftCount;
        long deltaRight = currentRightCount - lastRightCount;
        
        leftSpeed = (deltaLeft * MM_PER_PULSE) / deltaTime;
        rightSpeed = (deltaRight * MM_PER_PULSE) / deltaTime;
        
        lastLeftCount = currentLeftCount;
        lastRightCount = currentRightCount;
        lastUpdateTime = currentTime;
        
#if DEBUG_ENCODER
        Serial.printf("Speed L:%.1f R:%.1f mm/s\n", leftSpeed, rightSpeed);
#endif
    }
}

float MotorControl::getLeftSpeed() {
    return leftSpeed;
}

float MotorControl::getRightSpeed() {
    return rightSpeed;
}

void MotorControl::setCalibration(float leftCalib, float rightCalib) {
    this->leftCalib = constrain(leftCalib, 0.5, 1.5);
    this->rightCalib = constrain(rightCalib, 0.5, 1.5);
    Serial.printf("Motor calibration set: L=%.3f R=%.3f\n", this->leftCalib, this->rightCalib);
}

void MotorControl::setDeadband(int deadband) {
    this->deadband = constrain(deadband, 0, 100);
}

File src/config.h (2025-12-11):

#ifndef CONFIG_H
#define CONFIG_H

// ==================== GPIO引脚定义 ====================
// 超声波传感器
#define PIN_ULTRASONIC_TRIG   39
#define PIN_ULTRASONIC_ECHO   3

// 循迹模块 UART
#define PIN_LINE_TX          18
#define PIN_LINE_RX          17

// 声光报警
#define PIN_ALARM            46

// 右电机
#define PIN_MOTOR_R_I1       4
#define PIN_MOTOR_R_I2       5
#define PIN_ENCODER_R_A      10
#define PIN_ENCODER_R_B      9

// 左电机
#define PIN_MOTOR_L_I1       6
#define PIN_MOTOR_L_I2       7
#define PIN_ENCODER_L_A      11
#define PIN_ENCODER_L_B      12

// I2C1 (BMI160 + VL53L0X)
#define PIN_I2C1_SDA         16
#define PIN_I2C1_SCL         15

// I2C2 (OLED)
#define PIN_I2C2_SDA         14
#define PIN_I2C2_SCL         13

// 按键
#define PIN_BUTTON           1

// ==================== 车辆物理参数 ====================
#define CAR_LENGTH_CM        15.0      // 车长 cm
#define CAR_WIDTH_CM         19.18     // 车宽 cm
#define WHEEL_DIAMETER_MM    67.6      // 轮胎直径 mm
#define WHEEL_WIDTH_MM       26.4      // 轮胎宽度 mm
#define WHEEL_BASE_CM        15.0      // 轮距(估算) cm

// 编码器参数
#define ENCODER_PPR          11        // 每圈脉冲数
#define GEAR_RATIO           21.7      // 减速比
#define PULSES_PER_REV       (ENCODER_PPR * GEAR_RATIO * 4)  // AB相4倍频

// 车轮周长(mm)
#define WHEEL_CIRCUMFERENCE  (3.14159 * WHEEL_DIAMETER_MM)

// 脉冲到距离的转换系数 (mm/pulse)
#define MM_PER_PULSE         (WHEEL_CIRCUMFERENCE / PULSES_PER_REV)

// ==================== 传感器参数 ====================
#define LINE_SENSOR_COUNT    8
#define LINE_UART_BAUD       115200

// ==================== 控制参数 ====================
// PWM参数
#define PWM_FREQ             20000     // 20kHz PWM频率
#define PWM_RESOLUTION       8         // 8位分辨率 (0-255)
#define PWM_CHANNEL_R1       4
#define PWM_CHANNEL_R2       5
#define PWM_CHANNEL_L1       6
#define PWM_CHANNEL_L2       7

// 速度参数 (PWM值: 0-255)
#define SPEED_STOP           0
#define SPEED_SLOW           80        // 慢速(入库)
#define SPEED_NORMAL         150       // 正常巡线
#define SPEED_FAST           200       // 快速直线
#define SPEED_TURN           120       // 转弯速度

// PID参数 - 循迹 (电赛标准参数,可通过WebServer调整)
// 注意: 位置范围是 -1000~+1000, 输出差速PWM 0~255
#define KP_LINE              0.20     // 比例系数: 位置误差的响应速度
#define KI_LINE              0.005    // 积分系数: 消除稳态误差
#define KD_LINE              1.5      // 微分系数: 抑制振荡和超调

// 新增优化参数
#define PID_INTEGRAL_RANGE   200      // 积分分离阈值：误差小于此值才进行积分
#define MOTOR_DEADBAND       30       // 电机死区补偿PWM值 (根据电机特性调整)
#define MOTOR_SLEW_RATE      20       // 电机加速度限制 (每周期最大PWM变化量)

// 动态PID参数 (优化直线平顺度)
#define PID_SMALL_ERROR_THRES     150   // 直线判定阈值
#define PID_KP_SMALL_SCALE        0.6   // 直线时Kp缩放系数 (降低响应防抖动)
#define PID_KD_SMALL_SCALE        1.5   // 直线时Kd缩放系数 (增加阻尼防震荡)

// 超声波距离阈值 (cm)
#define OBSTACLE_DETECT_DIST 30        // 障碍物检测距离
#define OBSTACLE_SAFE_DIST   15        // 安全距离
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
